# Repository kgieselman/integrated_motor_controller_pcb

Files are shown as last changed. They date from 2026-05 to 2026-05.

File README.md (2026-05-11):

# Integrated Motor Controller PCB

A reusable base board for yearly robotics competitions. The base board handles drive, sensing, control, and radio. Per-season expansion is exposed through a small set of discrete headers (AUX, UART, QWIIC I²C, servo), not a single dedicated mechanism connector.

Adapter boards are named after creature parts: **Fang** (ping pong gripper/launcher), with future adapters extending the menagerie.

## Architecture

```
┌──────────────────────────────────────────────────────────────────┐
│                        Base Board                                │
│                                                                  │
│  ┌───────────────────┐  ┌──────────────────────────────────────┐ │
│  │ Power             │  │  STM32 H563RIT6                      │ │
│  │ 2S/3S → 5V ×2     │  │  250 MHz, 2MB / 640KB                │ │
│  │ (aux + main)      │  │  Y1 ASE-25MHz active oscillator      │ │
│  │ 5V → 3.3V LDO     │  │  BZ buzzer, D6–D9 LEDs               │ │
│  │ USB/batt PowerPath|  └────────────┬─────────────────────────┘ │
│  └───────────────────┘               │                           │
│                                      │                           │
│  ┌───────────────────────────────────┼───────────────┐           │
│  │   DRV8874 ×2 Motor Drivers        │               │           │
│  │   ~9A peak each                   │  Encoders ×2  │           │
│  │   IN1/IN2 + IPROPI                │  TIM4 / TIM8  │           │
│  └───────────────────────────────────┴───────────────┘           │
│                                                                  │
│  Connectors (* = DNP, footprint reserved):                       │
│   J1  RCVR    1×4 pin       — ELRS/CRSF RX/TX + 5 V *            │
│   J2  SWD     2×3 pin       — SWDIO/SWCLK/nRST, 3.3 V *          │
│   J3  ENC 0   1×3 pin       — encoder 0 signal, 3.3 V *          │
│   J4  ENC 1   1×3 pin       — encoder 1 signal, 3.3 V *          │
│   J5  UART    1×3 pin       — expansion UART, JST GH 1.25 mm *   │
│   J6  CH0     1×3 pin       — servo 0, +5V_Aux, GND *            │
│   J7  I2C     1×4 pin       — I2C SDA/SCL, JST SH 1.0 mm *       │
│   J8  CH1     1×3 pin       — servo 1, +5V_Aux, GND *            │
│   J9  I2C     1×4 pin       — I2C SDA/SCL (alt), JST SH 1.0 mm * │
│   J10 CH2     1×3 pin       — servo 2, +5V_Aux, GND *            │
│   J11 USB-C   USB 2.0       — debug / VBUS-powered logic         │
│   J12 VMeter  1×2 pin       — +BATT/GND for external voltmeter * │
│   J13 BATT    XT60          — 2S/3S LiPo input *                 │
│   J14 MOT 0   1×2 pin       — motor 0 out, Molex Micro-Fit 3.0 * │
│   J15 MOT 1   1×2 pin       — motor 1 out, Molex Micro-Fit 3.0 * │
│   JP1/JP2     solder jumpers — CRSF RX path (bridged by design)  │
└──────────────────────────────────────────────────────────────────┘
```

## Key Specs

| | |
|---|---|
| **MCU** | STM32H563RIT6 — Cortex-M33 @ 250 MHz, 2 MB flash, 640 KB SRAM, LQFP-64 |
| **Clock** | Y1 ASE-25.000MHZ — Abracon active oscillator, 4-pin SMD 3.2×2.5 mm |
| **Motor drivers** | 2× DRV8874 (PWP-16, HTSSOP) — IN1/IN2 mode (PMODE driven high), IPROPI current sense |
| **IMU** | LSM6DSV (U6) — 6-axis, SPI1 on PB3/PB4/PB5, CS=PC12, INT1=PD2, INT2=PB8; LGA-14 3×2.5 mm |
| **EEPROM** | M24C64 — 64 Kbit, I²C1 on PB6/PB7, WC=PA9 |
| **RC control** | External CRSF/ELRS receiver via J1 (1×4); JP1/JP2 solder jumpers bridged by default |
| **Servo channels** | 3, powered from +5V_Aux buck |
| **Expansion UART** | JST GH 1.25 mm |
| **I2C expansion** | JST SH 1.0 mm, 1×4 |
| **Power input** | 2S/3S LiPo (7.4–12.6 V) via XT60; USB-C VBUS can power logic rails only |
| **Power topology** | SW1 power switch; SI7157DP; 2N7002; AP63205WU bucks (5V_Aux + 5V); AP1117-33 LDO for 3.3 V |
| **Debug** | SWD, MCU RST, MCU BOOT0, USR button, power switch, LEDs, buzzer |
| **Board** | 4-layer FR4 |

## Schematic Hierarchy

```
integrated_motor_controller.kicad_sch (Root)
├── power_regulator_2s_3s.kicad_sch — Battery input, power switch, bucks, LDO, VBAT sense
├── mcu_h563r.kicad_sch             — STM32H563, Y1 active oscillator, bypass, pin assignments, VCAP, SW2/SW3
├── motor_driver_drv8874.kicad_sch  — DRV8874 (instantiated twice: Motor 0 + Motor 1), motor output connectors
├── imu_lsm6dsv.kicad_sch           — LSM6DSV on SPI1
├── eeprom_m24c64.kicad_sch         — M24C64 on I²C1
├── debug_leds.kicad_sch            — Debug LEDs (×4), buzzer, user button, transistor drivers
└── connector_usb.kicad_sch         — USB-C receptacle + USBLC6-2SC6 ESD + CC pulldowns
```

Servo, encoder, UART, I2C, RCVR, and SWD connectors are placed directly on the root sheet.

## Status

- [x] Schematic hierarchy defined
- [x] Sub-schematics created and wired
- [x] PCB layout complete (KiCad 10)
- [x] Gerber / drill files generated (`gerbers/`)
- [x] ERC clean
- [x] DRC clean
- [x] BOM and pick-and-place outputs
- [ ] First board assembled and tested

## Getting Started

1. Clone this repo
2. Open `integrated_motor_controller.kicad_pro` in KiCad 10+
3. Custom symbols are in `libraries/symbols/` — resolved via the committed `sym-lib-table`
4. Custom footprints are in `libraries/footprints/` — resolved via `fp-lib-table`

## Repo Structure

```
integrated_motor_controller-pcb/
├── integrated_motor_controller.kicad_pro              # KiCad project file — open this
├── integrated_motor_controller.kicad_sch              # Root schematic
├── integrated_motor_controller.kicad_pcb              # PCB layout
├── power_regulator_2s_3s.kicad_sch
├── mcu_h563r.kicad_sch
├── motor_driver_drv8874.kicad_sch
├── imu_lsm6dsv.kicad_sch
├── eeprom_m24c64.kicad_sch
├── debug_leds.kicad_sch
├── connector_usb.kicad_sch
├── gerbers/                       # Gerber + drill files (ready for fab)
├── output/
│   ├── integrated_motor_controller.csv                # BOM export
│   └── integrated_motor_controller.net                # Netlist export
├── libraries/
│   ├── symbols/                   # Custom KiCad symbol libraries (.kicad_sym)
│   ├── footprints/                # Custom KiCad footprint libraries (.kicad_mod)
│   └── 3d_models/                 # STEP/WRL 3D models
├── sym-lib-table                  # Symbol library table (committed — paths are relative)
└── fp-lib-table                   # Footprint library table (committed — paths are relative)
```

## License

[CERN Open Hardware Licence Version 2 - Strongly Reciprocal (CERN-OHL-S-2.0)](LICENSE) © 2026 Kyle Gieselman

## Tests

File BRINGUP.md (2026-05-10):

# Integrated Motor Controller — Bring-Up Notes

Sequencing and constraints for first-board bring-up.

---

## Power-On Sequence

### Pre-power checklist

1. Confirm no shorts on +BATT, 5V, 5V_AUX, 3V3 rails (continuity to GND).
2. Confirm USB-C (J11) and battery (J13) should not both be connected on first power-on.
3. Confirm Y1 (ASE-25.000MHZ) orientation — pin 1 marked with dot; OE pin must be driven or tied appropriately.

### Rail verification (battery path)

1. Connect bench supply to J13 (BATT_IN / XT60) at 7.4 V (2S nominal), current-limited to 500 mA.
2. Press SW1 (power switch).
3. Verify with multimeter:
   - TP9 = 5V ± 100 mV (U4 buck, main rail)
   - TP6 = 5V_AUX ± 100 mV (U2 buck, servo/aux rail)
   - TP8 = 3V3 ± 50 mV (U3 LDO)
   - TP7 = BATT_DIV — should be approximately V_BATT × R_low / (R_high + R_low). JLC resistors are intentionally kept here; per-board ADC calibration (see below) compensates for any divider tolerance.
4. Check current draw at idle (no MCU firmware) — expect < 50 mA.

### Rail verification (USB path)

1. Connect USB-C (J11) with no battery attached.
2. Verify TP8 = 3V3 (logic rails only; 5V bucks do not run from VBUS).
3. Verify TP9 and TP6 are near 0V (bucks off without battery).

---

## STM32 Programming

### SWD (J2) — primary path

J2 pinout (2×3, pin 1 top-left):

```
1  VCC_TARGET (3.3V)   2  SWDIO
3  GND                 4  SWDCLK
5  GND                 6  NRST
```

1. Connect J-Link or ST-Link to J2.
2. Supply power (SW1 on, battery connected, or USB-C connected for 3.3V).
3. Flash with OpenOCD or STM32CubeProgrammer targeting STM32H563RIT6.
4. To force BOOT0 (system bootloader for DFU): hold SW3 (BOOT), press SW2 (RST), release SW2, then release SW3.

---

## Motor Driver Bring-Up (DRV8874)

Both motor channels (U7 for Motor 0, U8 for Motor 1) share the same sheet — verify each independently.

1. Before connecting motors, confirm IPROPI resistor values are correct for expected current range.
2. With MCU firmware loaded, confirm PMODE is driven high (IN1/IN2 control mode).
3. Connect a small test motor to J14 (Motor 0) or J15 (Motor 1) and verify direction control and IPROPI feedback.
4. Do not exceed DRV8874 absolute maximum V_VM (65V); 2S/3S is well within range.

---

## External Receiver (J1)

J1 pinout (1×4, pin 1 = square pad):

```
1  GND
2  +5V
3  CRSF_RX  (MCU←, IO to receiver TX)
4  CRSF_TX  (MCU→, IO to receiver RX)
```

JP1 and JP2 are bridged by default — the CRSF UART is a direct MCU↔J1 connection. No jumper changes required for normal operation.

To connect an ELRS receiver: wire receiver TX → J1 pin 3, receiver RX → J1 pin 4.

---

## Battery Voltage Sense Calibration

The VBAT_SENSE divider uses JLC resistors (not precision-tolerance parts). Each board must be calibrated individually to remove the divider error from ADC readings.

**Procedure (per board):**

1. Connect the calibrated DC supply to J8. Set a known voltage in the 6–9 V range (typical 2S window).
2. Run the ADC calibration routine in the bringup firmware (trigger TBD).
3. The routine samples `ADC1_INP4` (PC4), computes the scale factor against the known supply voltage, and stores the result in EEPROM (address TBD).
4. `Battery.hpp` must apply this stored scale factor at runtime instead of using nominal divider math.
5. Repeat at a second setpoint to verify linearity before signing off.

> **Note:** The calibration trigger mechanism has not been decided yet. Options include a dedicated console command (`cal vbat`), a button-hold sequence at boot, or a flag byte in EEPROM. Update this section once the approach is settled.

---

## Notes

- **SW2** = MCU RST (active low, pulls NRST)
- **SW3** = MCU BOOT0 (hold during reset to enter system bootloader)
- **SW4** = USR (user debug button)
- **SW1** = board power (series with Q1 gate drive)
- **D6** = LED0, **D7** = LED1, **D8** = LED2 — debug LEDs driven by MCU GPIOs; **D9** = PWR indicator LED
- **BZ** = buzzer driven by MCU GPIO; D10 is flyback protection
- **J12** = VMeter — exposes +BATT and GND for an external battery voltage display

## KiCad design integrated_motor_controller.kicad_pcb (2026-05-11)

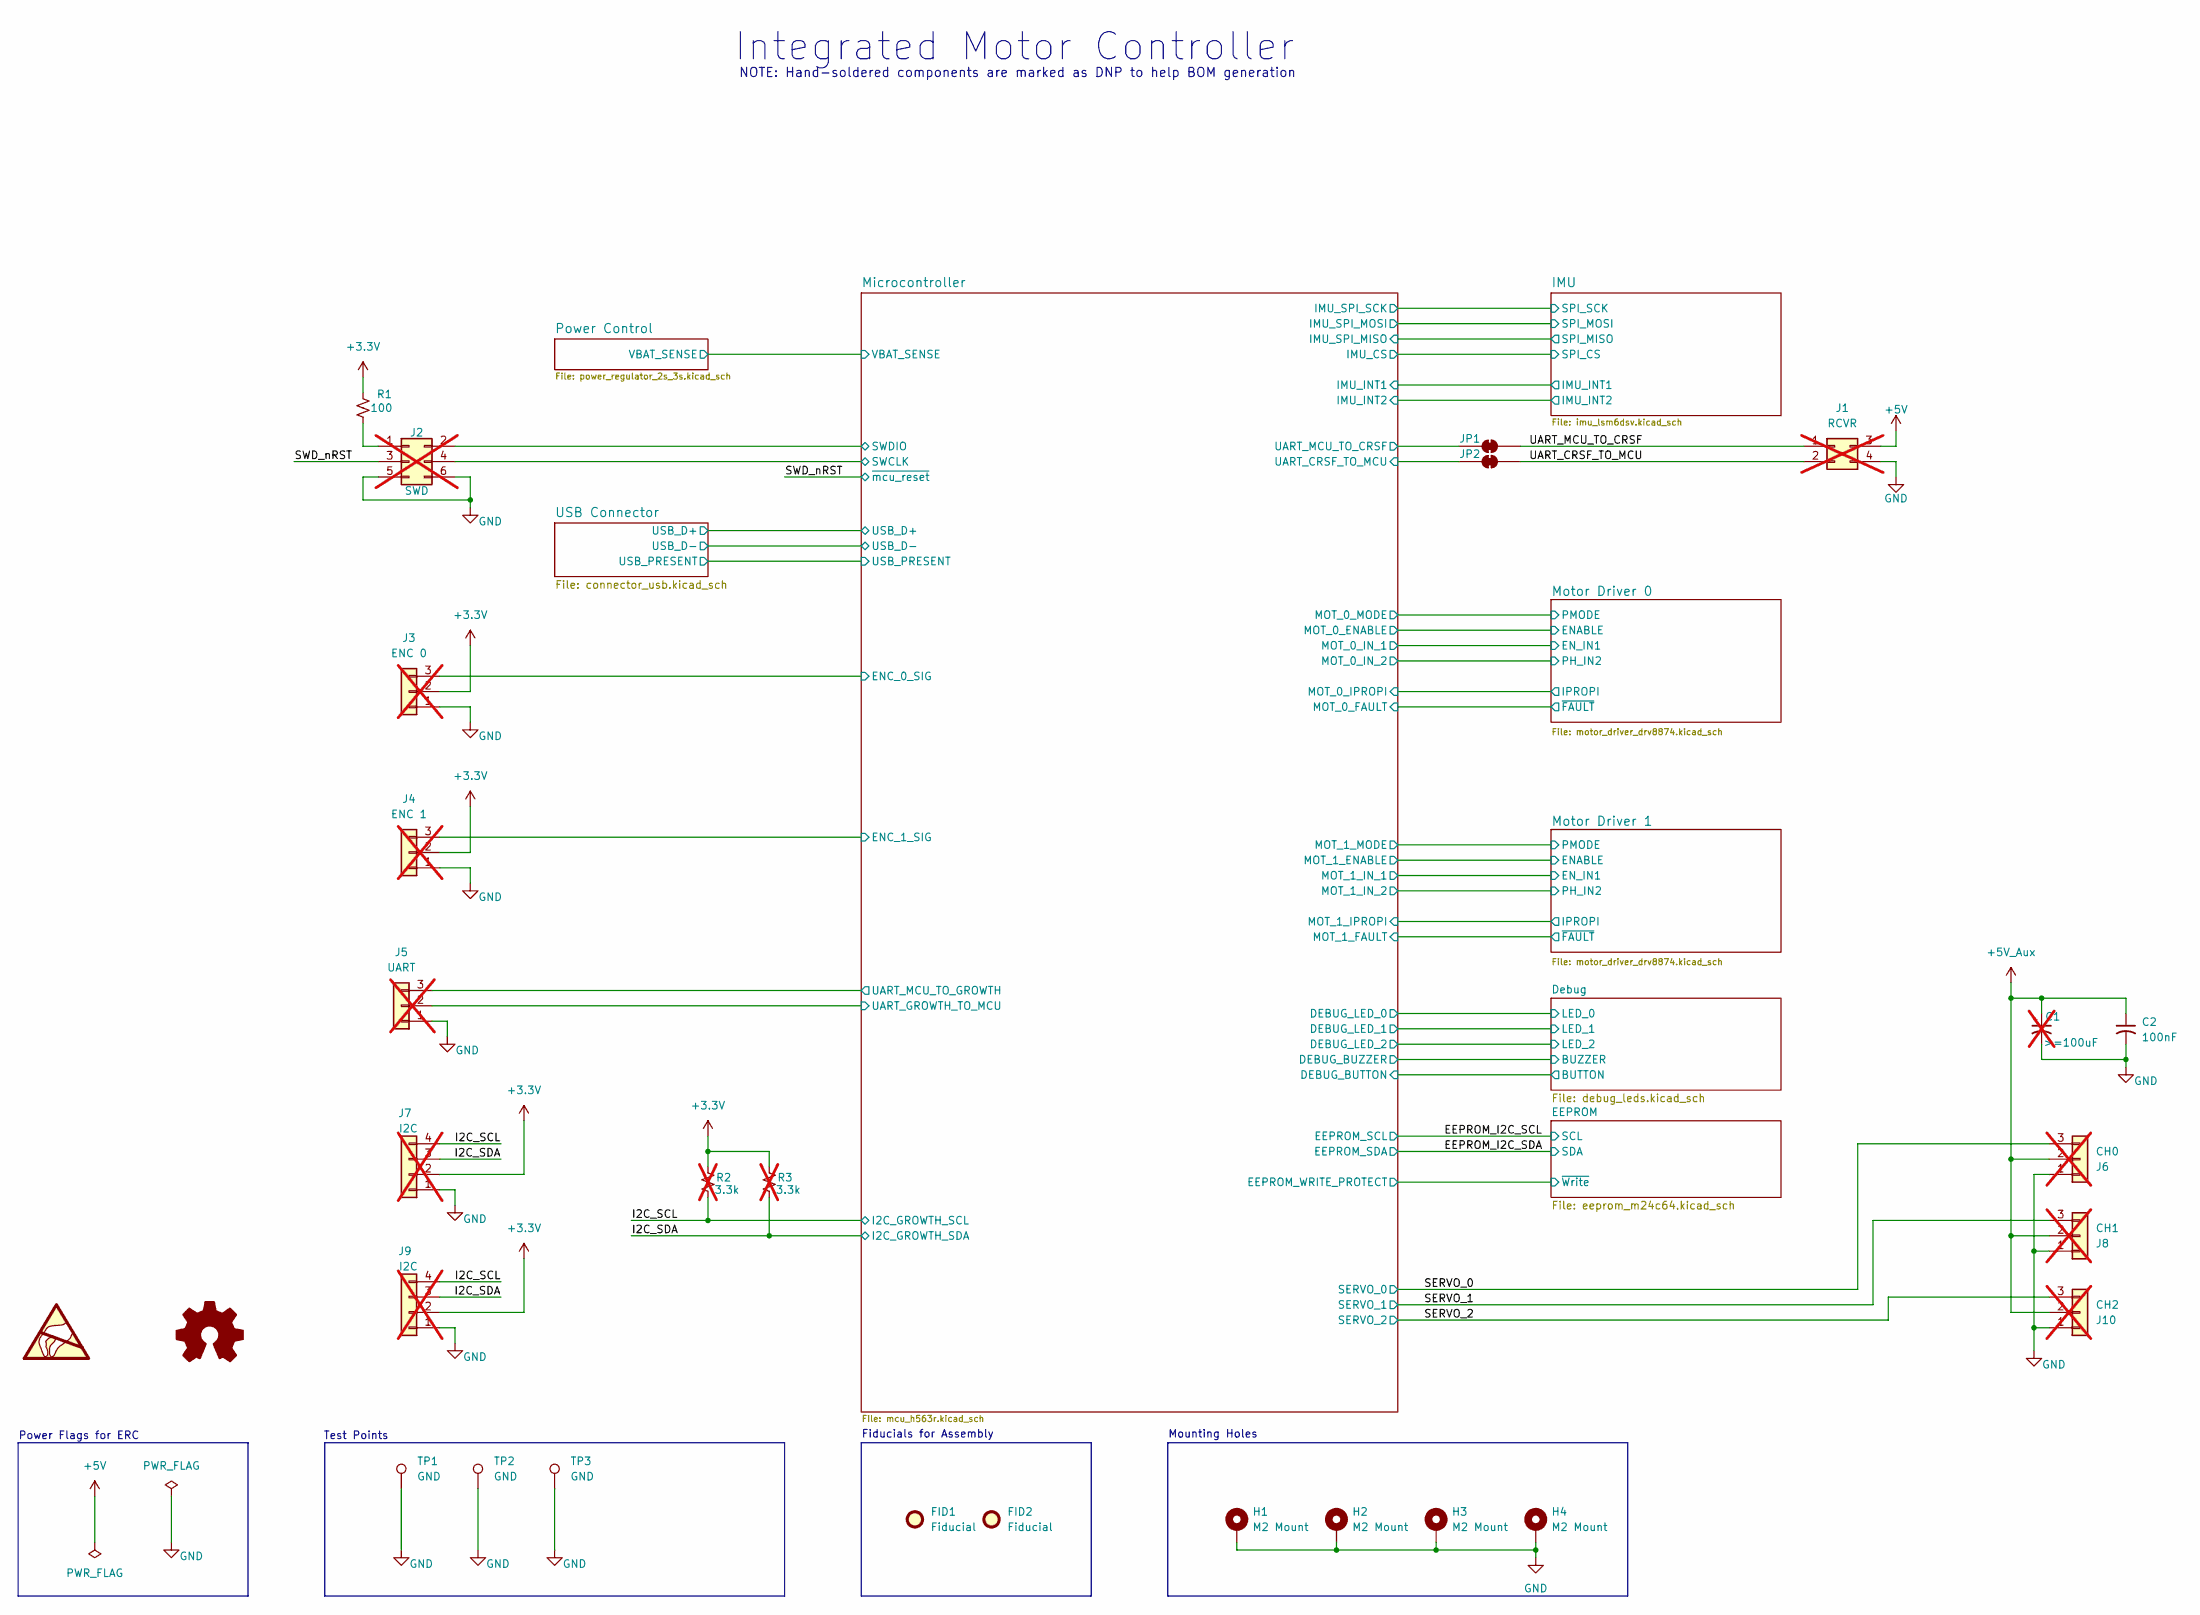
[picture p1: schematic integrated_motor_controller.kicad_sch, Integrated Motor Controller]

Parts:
C1: >=100uF; CP_Radial_D5.0mm_P2.00mm; Part No ---; JLCPCB ---; not fitted
C2: 100nF; C_0603_1608Metric; Part No CC0603KRX7R9BB104; JLCPCB C14663
FID1, FID2: Fiducial; ToolingHole_1.152mm; Part No ---; JLCPCB ---
H1, H2, H3, H4: M2 Mount; MountingHole_2.2mm_M2_Pad_Via; Part No ---; JLCPCB ---
J1: RCVR; PinHeader_1x04_P2.54mm_Vertical; Part No ---; JLCPCB ---; not fitted
J2: SWD; PinHeader_2x03_P2.54mm_Vertical; Part No ---; JLCPCB ---; not fitted
J3: ENC 0; PinHeader_1x03_P2.54mm_Vertical; Part No ---; JLCPCB ---; not fitted
J4: ENC 1; PinHeader_1x03_P2.54mm_Vertical; Part No ---; JLCPCB ---; not fitted
J5: UART; JST_GH_BM03B-GHS-TBT_1x03-1MP_P1.25mm_Vertical; Part No TODO; JLCPCB ---; not fitted
J6: CH0; PinHeader_1x03_P2.54mm_Vertical; Part No ----; JLCPCB ----; not fitted
J7, J9: I2C; JST_SH_BM04B-SRSS-TB_1x04-1MP_P1.00mm_Vertical; Part No TODO; JLCPCB ---; not fitted
J8: CH1; PinHeader_1x03_P2.54mm_Vertical; Part No ----; JLCPCB ----; not fitted
J10: CH2; PinHeader_1x03_P2.54mm_Vertical; Part No ----; JLCPCB ----; not fitted
JP1, JP2: SolderJumper_2_Bridged; SolderJumper-2_P1.3mm_Bridged_Pad1.0x1.5mm; Part No ---; JLCPCB ---
R1: 100; R_0603_1608Metric; Part No 0603WAF1000T5E; JLCPCB C22775
R2, R3: 3.3k; R_0603_1608Metric; Part No 0603WAF3301T5E; JLCPCB C22978; not fitted
SYM1: SYM_ESD_Large; ESD-Logo_6.6x6mm_SilkScreen; Part No ---; JLCPCB ---
SYM2: Logo_Open_Hardware_Small; KiCad-Logo2_6mm_SilkScreen; Part No ---; JLCPCB ---
TP1, TP2, TP3: GND; TestPoint_Pad_D1.0mm; Part No ---; JLCPCB ---

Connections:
+5V: J1.3; also elsewhere on the board
+5V_Aux: C1.1, C2.1, J6.2, J8.2, J10.2; also elsewhere on the board
/I2C_SCL: J7.4, J9.4, R2.1; also elsewhere on the board
/I2C_SDA: J7.3, J9.3, R3.1; also elsewhere on the board
/Microcontroller/ENC_0_SIG: J3.3; also elsewhere on the board
/Microcontroller/ENC_1_SIG: J4.3; also elsewhere on the board
/Microcontroller/SWCLK: J2.4; also elsewhere on the board
/Microcontroller/SWDIO: J2.2; also elsewhere on the board
/Microcontroller/UART_CRSF_TO_MCU: JP2.1 (A); also elsewhere on the board
/Microcontroller/UART_GROWTH_TO_MCU: J5.2; also elsewhere on the board
/Microcontroller/UART_MCU_TO_CRSF: JP1.1 (A); also elsewhere on the board
/Microcontroller/UART_MCU_TO_GROWTH: J5.3; also elsewhere on the board
/SERVO_0: J6.3; also elsewhere on the board
/SERVO_1: J8.3; also elsewhere on the board
/SERVO_2: J10.3; also elsewhere on the board
/SWD_nRST: J2.3; also elsewhere on the board
/UART_CRSF_TO_MCU: J1.2, JP2.2 (B)
/UART_MCU_TO_CRSF: J1.1, JP1.2 (B)
unnamed: J2.1, R1.2

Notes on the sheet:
Fiducials for Assembly
Test Points
Integrated Motor Controller
Power Flags for ERC
Mounting Holes
NOTE: Hand-soldered components are marked as DNP to help BOM generation

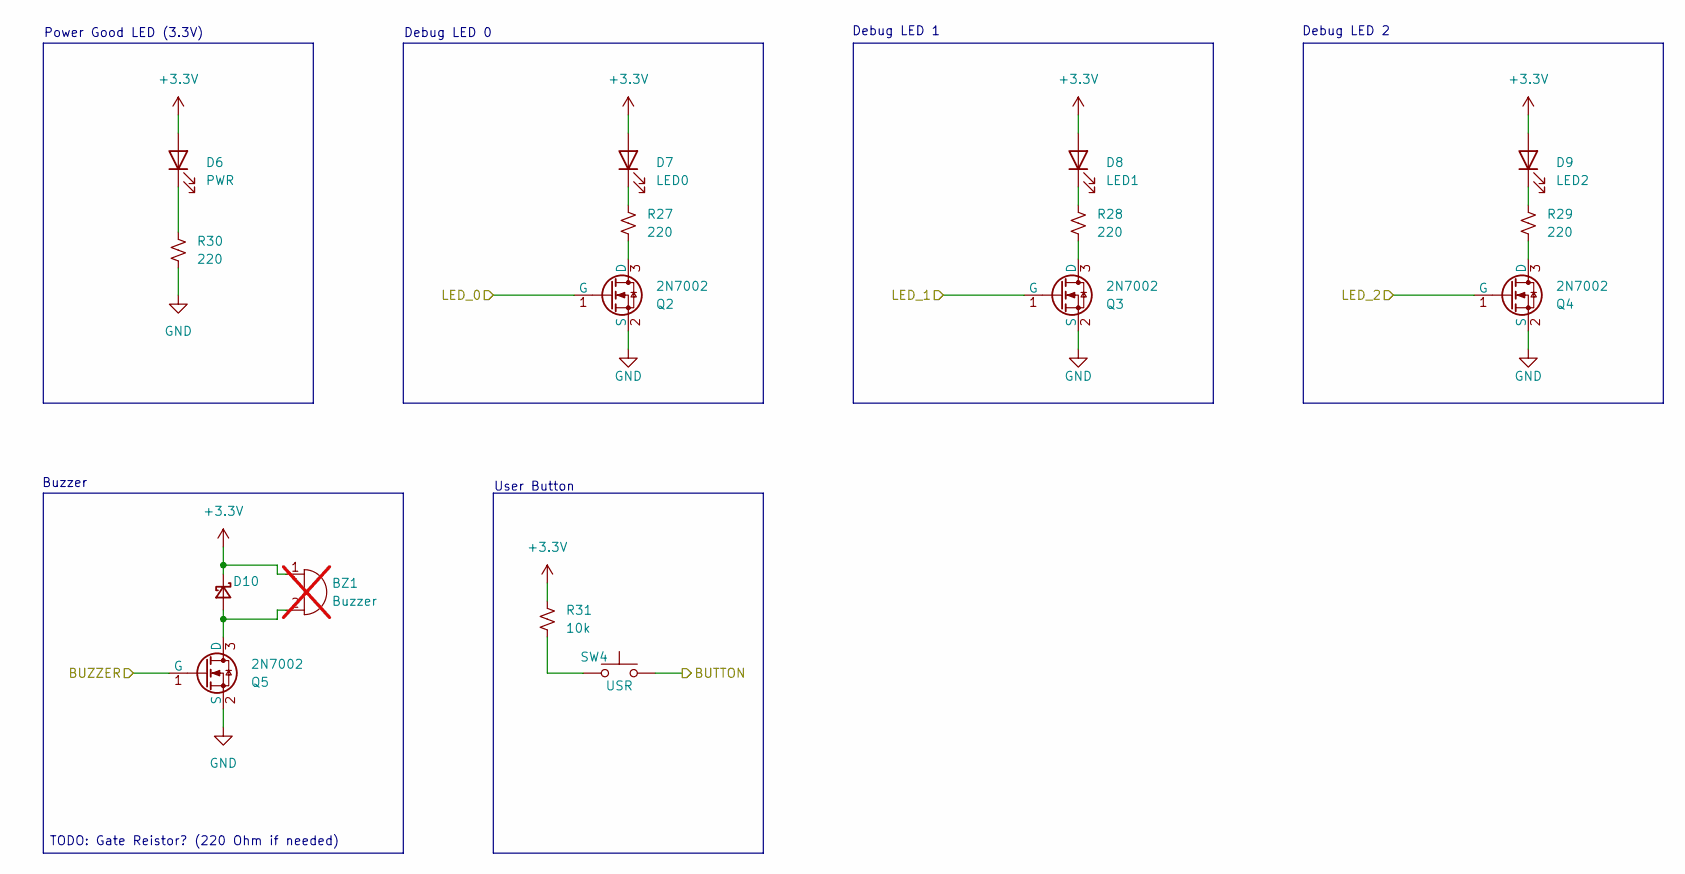
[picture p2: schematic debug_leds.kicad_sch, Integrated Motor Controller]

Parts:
BZ1: Buzzer; MagneticBuzzer_PUI_AT-0927-TT-6-R; Part No AT-0927-TT-6-R; JLCPCB ---; not fitted
D6: PWR; LED_0603_1608Metric; Part No KT-0603R; JLCPCB C2286
D7: LED0; LED_0603_1608Metric; Part No KT-0603R; JLCPCB C2286
D8: LED1; LED_0603_1608Metric; Part No KT-0603R; JLCPCB C2286
D9: LED2; LED_0603_1608Metric; Part No KT-0603R; JLCPCB C2286
D10: Schottky; D_SOD-123; Part No B5819W SL; JLCPCB C8598
Q2, Q3, Q4, Q5: 2N7002; SOT-23; Part No 2N7002; JLCPCB C8545
R27, R28, R29, R30: 220; R_0603_1608Metric; Part No 0603WAF2200T5E; JLCPCB C22962
R31: 10k; R_0603_1608Metric; Part No 0603WAF1002T5E; JLCPCB C25804
SW4: USR; SW_SPST_TS-1088-xR020; Part No TS-1088-AR02016; JLCPCB C720477

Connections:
/Debug/BUTTON: SW4.2; also elsewhere on the board
/Debug/BUZZER: Q5.1 (G); also elsewhere on the board
/Debug/LED_0: Q2.1 (G); also elsewhere on the board
/Debug/LED_1: Q3.1 (G); also elsewhere on the board
/Debug/LED_2: Q4.1 (G); also elsewhere on the board
unnamed: BZ1.2 (-), D10.2 (A), Q5.3 (D)
unnamed: D7.1 (K), R27.1
unnamed: D8.1 (K), R28.1
unnamed: Q2.3 (D), R27.2
unnamed: Q3.3 (D), R28.2
unnamed: R31.1, SW4.1

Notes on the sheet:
Debug LED 2
Buzzer
User Button
Debug LED 0
Power Good LED (3.3V)
Debug LED 1
TODO: Gate Reistor? (220 Ohm if needed)

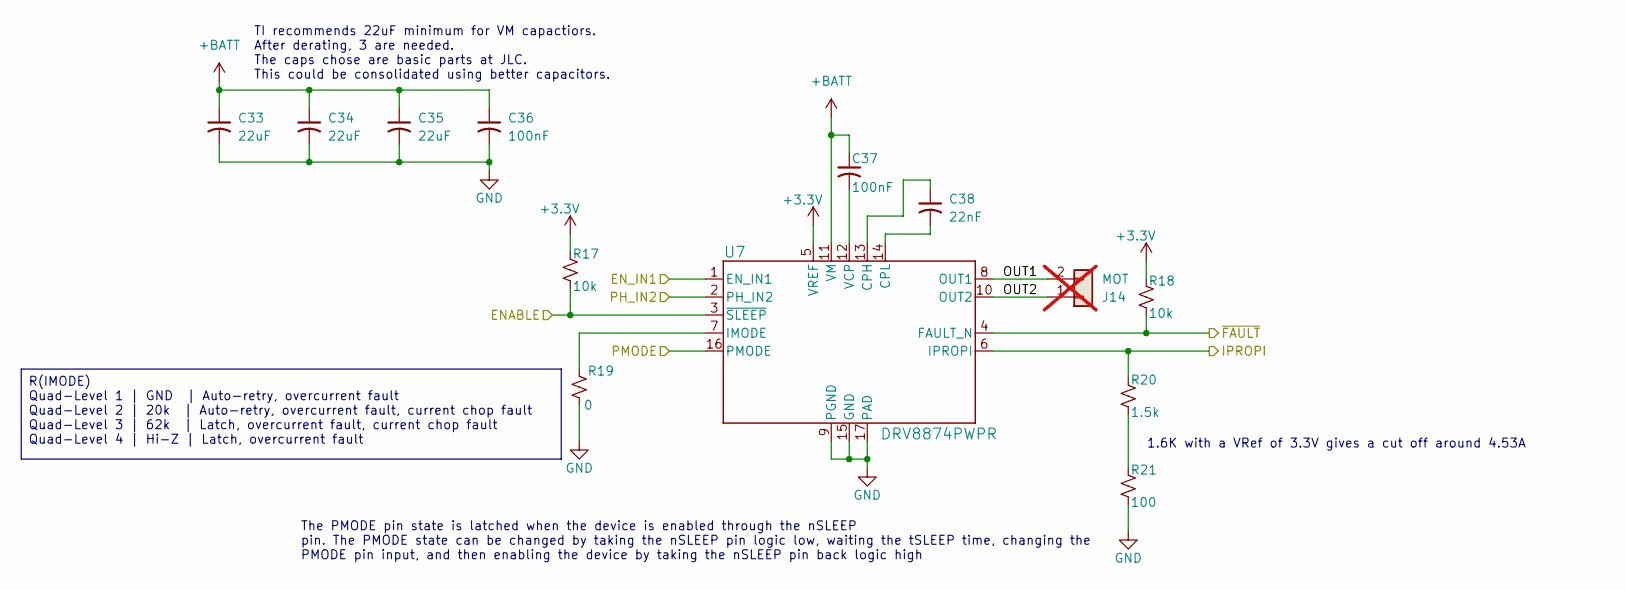
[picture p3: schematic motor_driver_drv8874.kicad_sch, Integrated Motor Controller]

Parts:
C33, C34, C35: 22uF; C_1206_3216Metric; Part No CL31A226KAHNNNE; JLCPCB C12891
C36, C37: 100nF; C_0603_1608Metric; Part No CC0603KRX7R9BB104; JLCPCB C14663
C38: 22nF; C_0603_1608Metric; Part No CL10B223KB8NNNC; JLCPCB C21122
J14: MOT; Molex_Micro-Fit_3.0_43650-0215_1x02_P3.00mm_Vertical; Part No 0436500215; JLCPCB ---; not fitted
R17, R18: 10k; R_0603_1608Metric; Part No 0603WAF1002T5E; JLCPCB C25804
R19: 0; R_0805_2012Metric; Part No 0805W8F0000T5E; JLCPCB C17477
R20: 1.5k; R_0805_2012Metric; Part No 0805W8F1501T5E; JLCPCB C4310
R21: 100; R_0805_2012Metric; Part No 0805W8F1000T5E; JLCPCB C17408
U7: DRV8874PWPR; PWP0016J_N; Part No DRV8874PWPR; JLCPCB C1855818

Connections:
+BATT: C33.1, C34.1, C35.1, C36.1, C37.1, U7.11 (VM); also elsewhere on the board
/Microcontroller/MOT_0_ENABLE: R17.1, U7.3 (~SLEEP); also elsewhere on the board
/Microcontroller/MOT_0_FAULT: R18.1, U7.4 (FAULT_N); also elsewhere on the board
/Microcontroller/MOT_0_IN_1: U7.1 (EN_IN1); also elsewhere on the board
/Microcontroller/MOT_0_IN_2: U7.2 (PH_IN2); also elsewhere on the board
/Microcontroller/MOT_0_IPROPI: R20.2, U7.6 (IPROPI); also elsewhere on the board
/Microcontroller/MOT_0_MODE: U7.16 (PMODE); also elsewhere on the board
/Motor Driver 0/OUT1: J14.2, U7.8 (OUT1)
/Motor Driver 0/OUT2: J14.1, U7.10 (OUT2)
unnamed: R20.1, R21.2
unnamed: C38.1, U7.13 (CPH)
unnamed: C38.2, U7.14 (CPL)
unnamed: R19.1, U7.7 (IMODE)
unnamed: C37.2, U7.12 (VCP)

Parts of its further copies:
C39, C40, C41: 22uF; C_1206_3216Metric; Part No CL31A226KAHNNNE; JLCPCB C12891
C42, C43: 100nF; C_0603_1608Metric; Part No CC0603KRX7R9BB104; JLCPCB C14663
C44: 22nF; C_0603_1608Metric; Part No CL10B223KB8NNNC; JLCPCB C21122
J15: MOT; Molex_Micro-Fit_3.0_43650-0215_1x02_P3.00mm_Vertical; Part No 0436500215; JLCPCB ---; not fitted
R22, R23: 10k; R_0603_1608Metric; Part No 0603WAF1002T5E; JLCPCB C25804
R24: 0; R_0805_2012Metric; Part No 0805W8F0000T5E; JLCPCB C17477
R25: 1.5k; R_0805_2012Metric; Part No 0805W8F1501T5E; JLCPCB C4310
R26: 100; R_0805_2012Metric; Part No 0805W8F1000T5E; JLCPCB C17408
U8: DRV8874PWPR; PWP0016J_N; Part No DRV8874PWPR; JLCPCB C1855818

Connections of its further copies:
+BATT: C39.1, C40.1, C41.1, C42.1, C43.1, U8.11 (VM); also elsewhere on the board
/Microcontroller/MOT_1_ENABLE: R22.1, U8.3 (~SLEEP); also elsewhere on the board
/Microcontroller/MOT_1_FAULT: R23.1, U8.4 (FAULT_N); also elsewhere on the board
/Microcontroller/MOT_1_IN_1: U8.1 (EN_IN1); also elsewhere on the board
/Microcontroller/MOT_1_IN_2: U8.2 (PH_IN2); also elsewhere on the board
/Microcontroller/MOT_1_IPROPI: R25.2, U8.6 (IPROPI); also elsewhere on the board
/Microcontroller/MOT_1_MODE: U8.16 (PMODE); also elsewhere on the board
/Motor Driver 1/OUT1: J15.2, U8.8 (OUT1)
/Motor Driver 1/OUT2: J15.1, U8.10 (OUT2)
unnamed: R25.1, R26.2
unnamed: C44.1, U8.13 (CPH)
unnamed: C44.2, U8.14 (CPL)
unnamed: R24.1, U8.7 (IMODE)
unnamed: C43.2, U8.12 (VCP)

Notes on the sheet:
1.6K with a VRef of 3.3V gives a cut off around 4.53A
The PMODE pin state is latched when the device is enabled through the nSLEEP pin. The PMODE state can be changed by taking the nSLEEP pin logic low, waiting the tSLEEP time, changing the PMODE pin input, and then enabling the device by taking the nSLEEP pin back logic high
TI recommends 22uF minimum for VM capactiors. After derating, 3 are needed. The caps chose are basic parts at JLC. This could be consolidated using better capacitors.
R(IMODE) Quad-Level 1 | GND | Auto-retry, overcurrent fault Quad-Level 2 | 20k | Auto-retry, overcurrent fault, current chop fault Quad-Level 3 | 62k | Latch, overcurrent fault, current chop fault Quad-Level 4 | Hi-Z | Latch, overcurrent fault

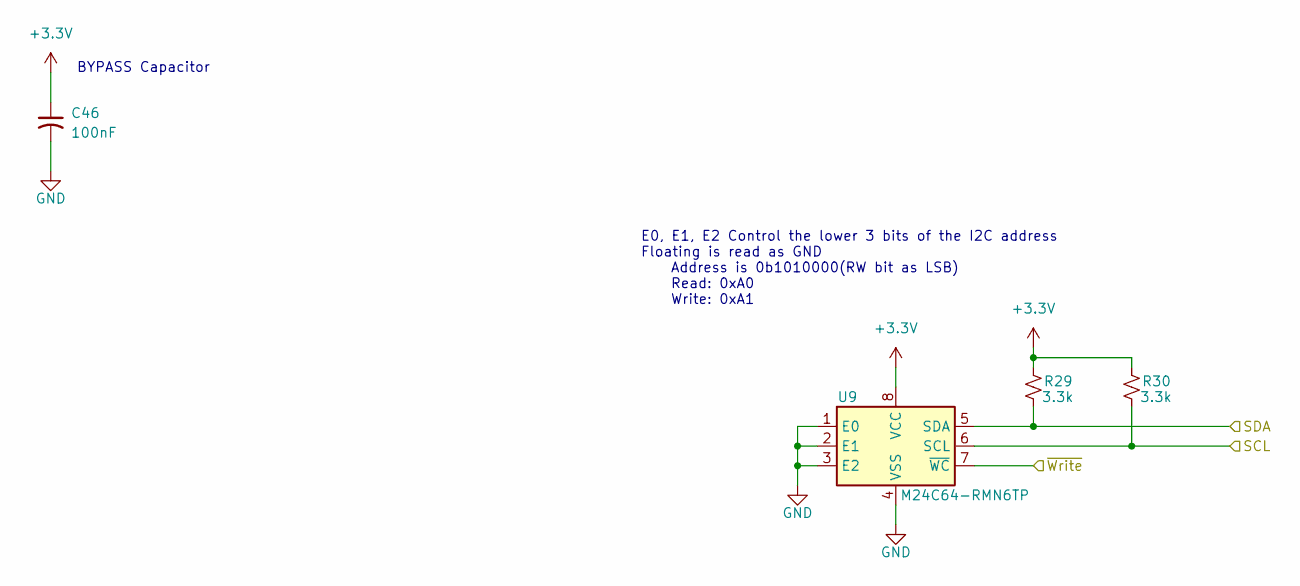
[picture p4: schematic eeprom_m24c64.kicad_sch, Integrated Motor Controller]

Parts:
C46: 100nF; C_0603_1608Metric; Part No CC0603KRX7R9BB104; JLCPCB C14663
R29, R30: 3.3k; R_0603_1608Metric; Part No 0603WAF3301T5E; JLCPCB C22978
U9: M24C64-RMN6TP; SOIC-8_3.9x4.9mm_P1.27mm; Part No M24C64-RMN6TP; JLCPCB C79988

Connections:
/EEPROM/~Write: U9.7 (~WC); also elsewhere on the board

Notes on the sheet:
E0, E1, E2 Control the lower 3 bits of the I2C address Floating is read as GND Address is 0b1010000(RW bit as LSB) Read: 0xA0 Write: 0xA1
BYPASS Capacitor

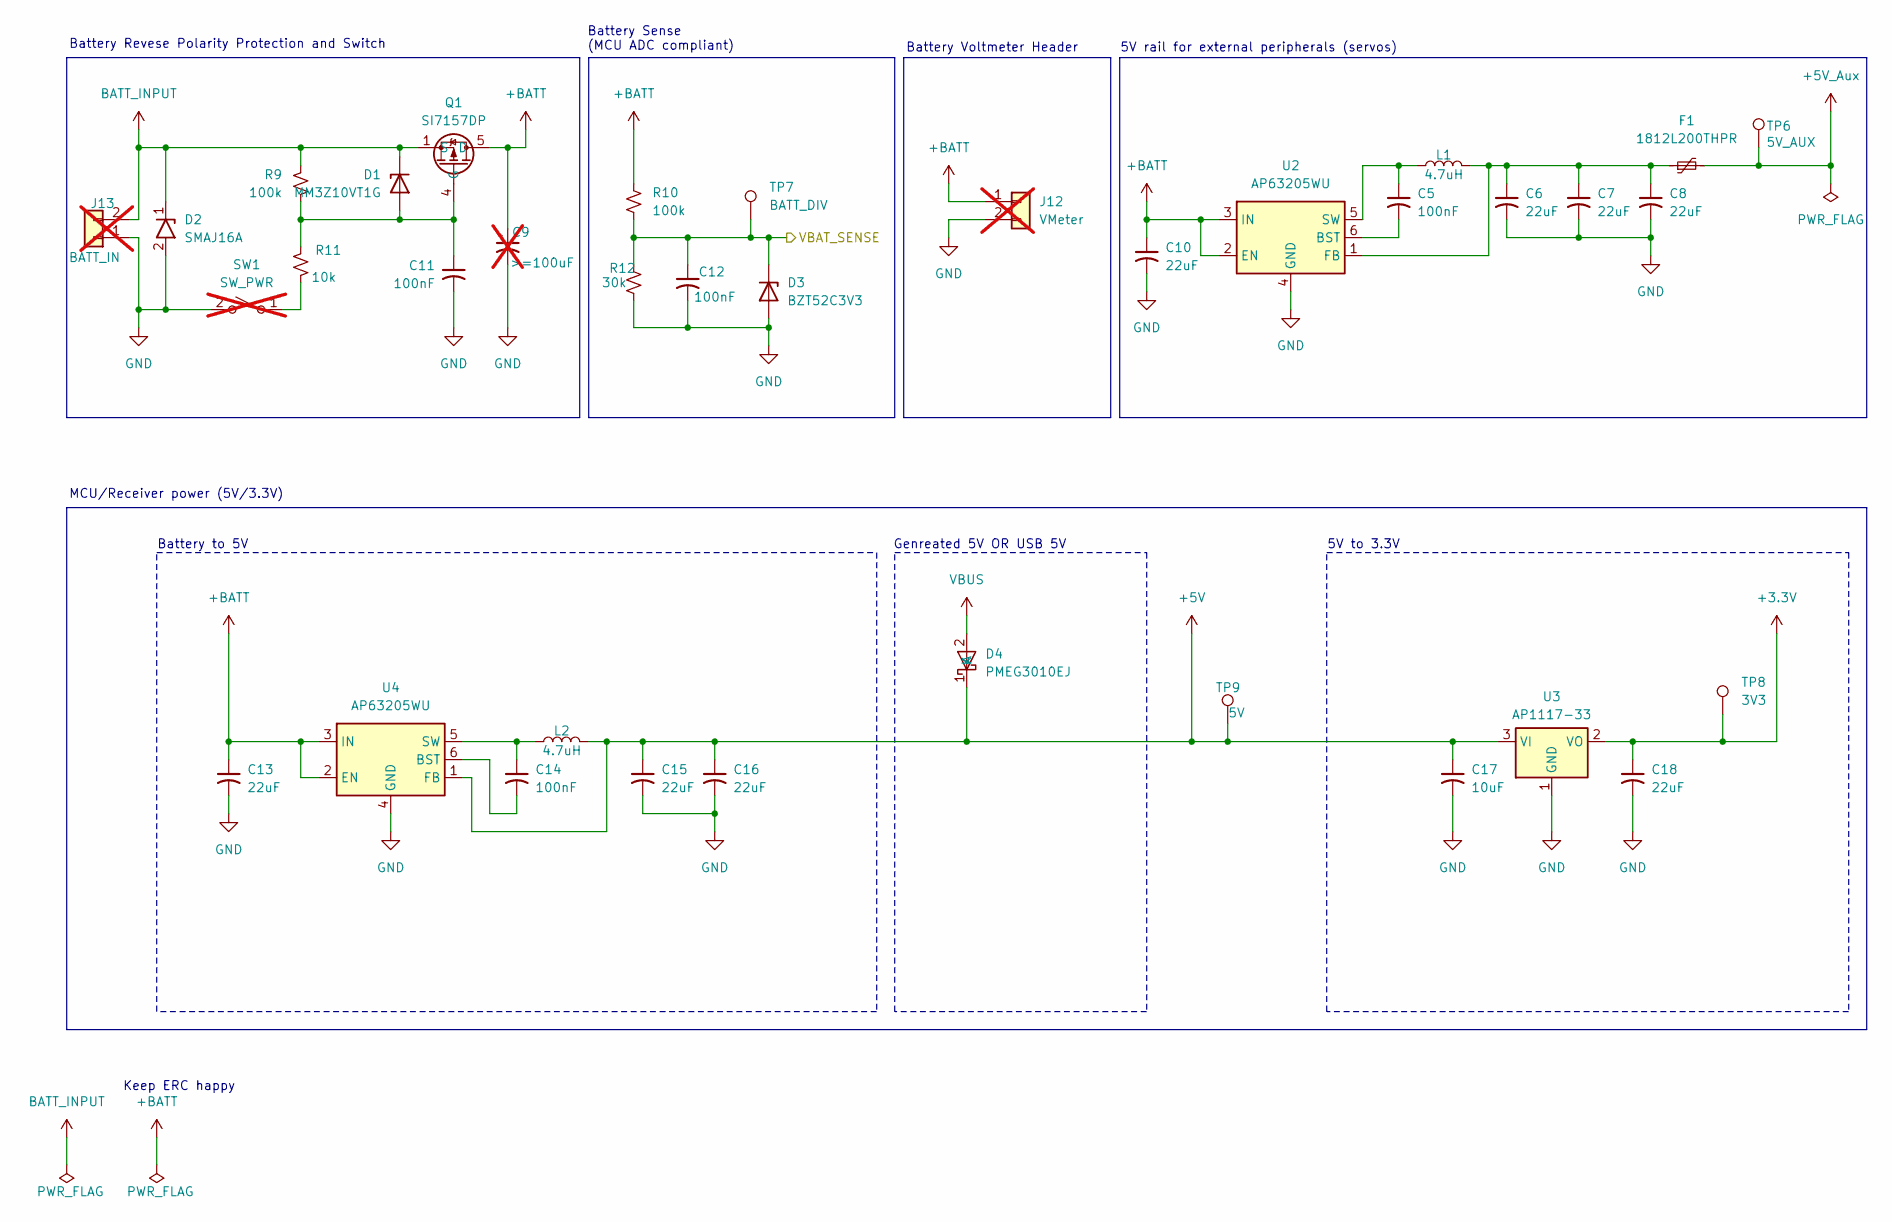
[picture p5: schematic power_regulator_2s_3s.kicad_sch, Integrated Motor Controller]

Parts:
C5, C11, C12, C14: 100nF; C_0603_1608Metric; Part No CC0603KRX7R9BB104; JLCPCB C14663
C6, C7, C8, C10, C13, C15, C16, C18: 22uF; C_1206_3216Metric; Part No CL31A226KAHNNNE; JLCPCB C12891
C9: >=100uF; CP_Radial_D5.0mm_P2.00mm; Part No ---; JLCPCB ---; not fitted
C17: 10uF; C_0603_1608Metric; Part No CL10A106MA8NRNC; JLCPCB C96446
D1: MM3Z10VT1G; D_SOD-323; Part No MM3Z10VT1G; JLCPCB C39057
D2: SMAJ16A; D_SMA; Part No SMAJ16A; JLCPCB C74561
D3: BZT52C3V3; D_SOD-123; Part No BZT52C3V3-7-F; JLCPCB C151564
D4: PMEG3010EJ; D_SOD-323F; Part No PMEG3010EJ,115; JLCPCB C255586
F1: 1812L200THPR; Fuse_1812_4532Metric; Part No 1812L200THPR; JLCPCB C207074
J12: VMeter; PinHeader_1x02_P2.54mm_Vertical; Part No ---; JLCPCB ---; not fitted
J13: BATT_IN; AMASS_XT60-M_1x02_P7.20mm_Vertical; Part No ---; JLCPCB ---; not fitted
L1, L2: 4.7uH; L_Sunlord_MWSA0503S; Part No MWSA0503S-4R7MT; JLCPCB C408410
Q1: SI7157DP; PowerPAK_SO-8_Single; Part No SI7157DP-T1-GE3; JLCPCB C3279562
R9, R10: 100k; R_0603_1608Metric; Part No 0603WAF1003T5E; JLCPCB C25803
R11: 10k; R_0603_1608Metric; Part No 0603WAF1002T5E; JLCPCB C25804
R12: 30k; R_0603_1608Metric; Part No 0603WAF3002T5E; JLCPCB C22984
SW1: SW_PWR; PinHeader_1x02_P2.54mm_Vertical; Part No ---; JLCPCB ---; not fitted
TP6: 5V_AUX; TestPoint_Pad_D1.0mm; Part No ---; JLCPCB ---
TP7: BATT_DIV; TestPoint_Pad_D1.0mm; Part No ---; JLCPCB ---
TP8: 3V3; TestPoint_Pad_D1.0mm; Part No ---; JLCPCB ---
TP9: 5V; TestPoint_Pad_D1.0mm; Part No ---; JLCPCB ---
U2, U4: AP63205WU; TSOT-23-6; Part No AP63205WU-7; JLCPCB C2071056
U3: AP1117-33; SOT-223-3_TabPin2; Part No AMS1117-3.3; JLCPCB C6186

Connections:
+5V: C15.1, C16.1, C17.1, D4.1 (K), L2.2, TP9.1 (1_1), U3.3 (VI), U4.1 (FB); also elsewhere on the board
+5V_Aux: F1.2, TP6.1 (1_1); also elsewhere on the board
+BATT: C9.1, C10.1, C13.1, J12.1, Q1.5 (D), R10.1, U2.2 (EN), U2.3 (IN), U4.2 (EN), U4.3 (IN); also elsewhere on the board
/Microcontroller/VBAT_SENSE: C12.1, D3.1 (K), R10.2, R12.1, TP7.1 (1_1); also elsewhere on the board
BATT_INPUT: D1.1 (K), D2.1 (A1), J13.2, Q1.1 (S), Q1.2 (S), Q1.3 (S), R9.2
unnamed: C11.1, D1.2 (A), Q1.4 (G), R9.1, R11.2
unnamed: R11.1, SW1.1 (A)
unnamed: C5.2, U2.6 (BST)
unnamed: C6.1, C7.1, C8.1, F1.1, L1.2, U2.1 (FB)
unnamed: C5.1, L1.1, U2.5 (SW)
unnamed: C14.2, U4.6 (BST)
unnamed: C14.1, L2.1, U4.5 (SW)
VBUS: D4.2 (A); also elsewhere on the board

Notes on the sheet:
Battery to 5V
Battery Sense (MCU ADC compliant)
Battery Revese Polarity Protection and Switch
Battery Voltmeter Header
5V to 3.3V
MCU/Receiver power (5V/3.3V)
Keep ERC happy
Genreated 5V OR USB 5V
5V rail for external peripherals (servos)

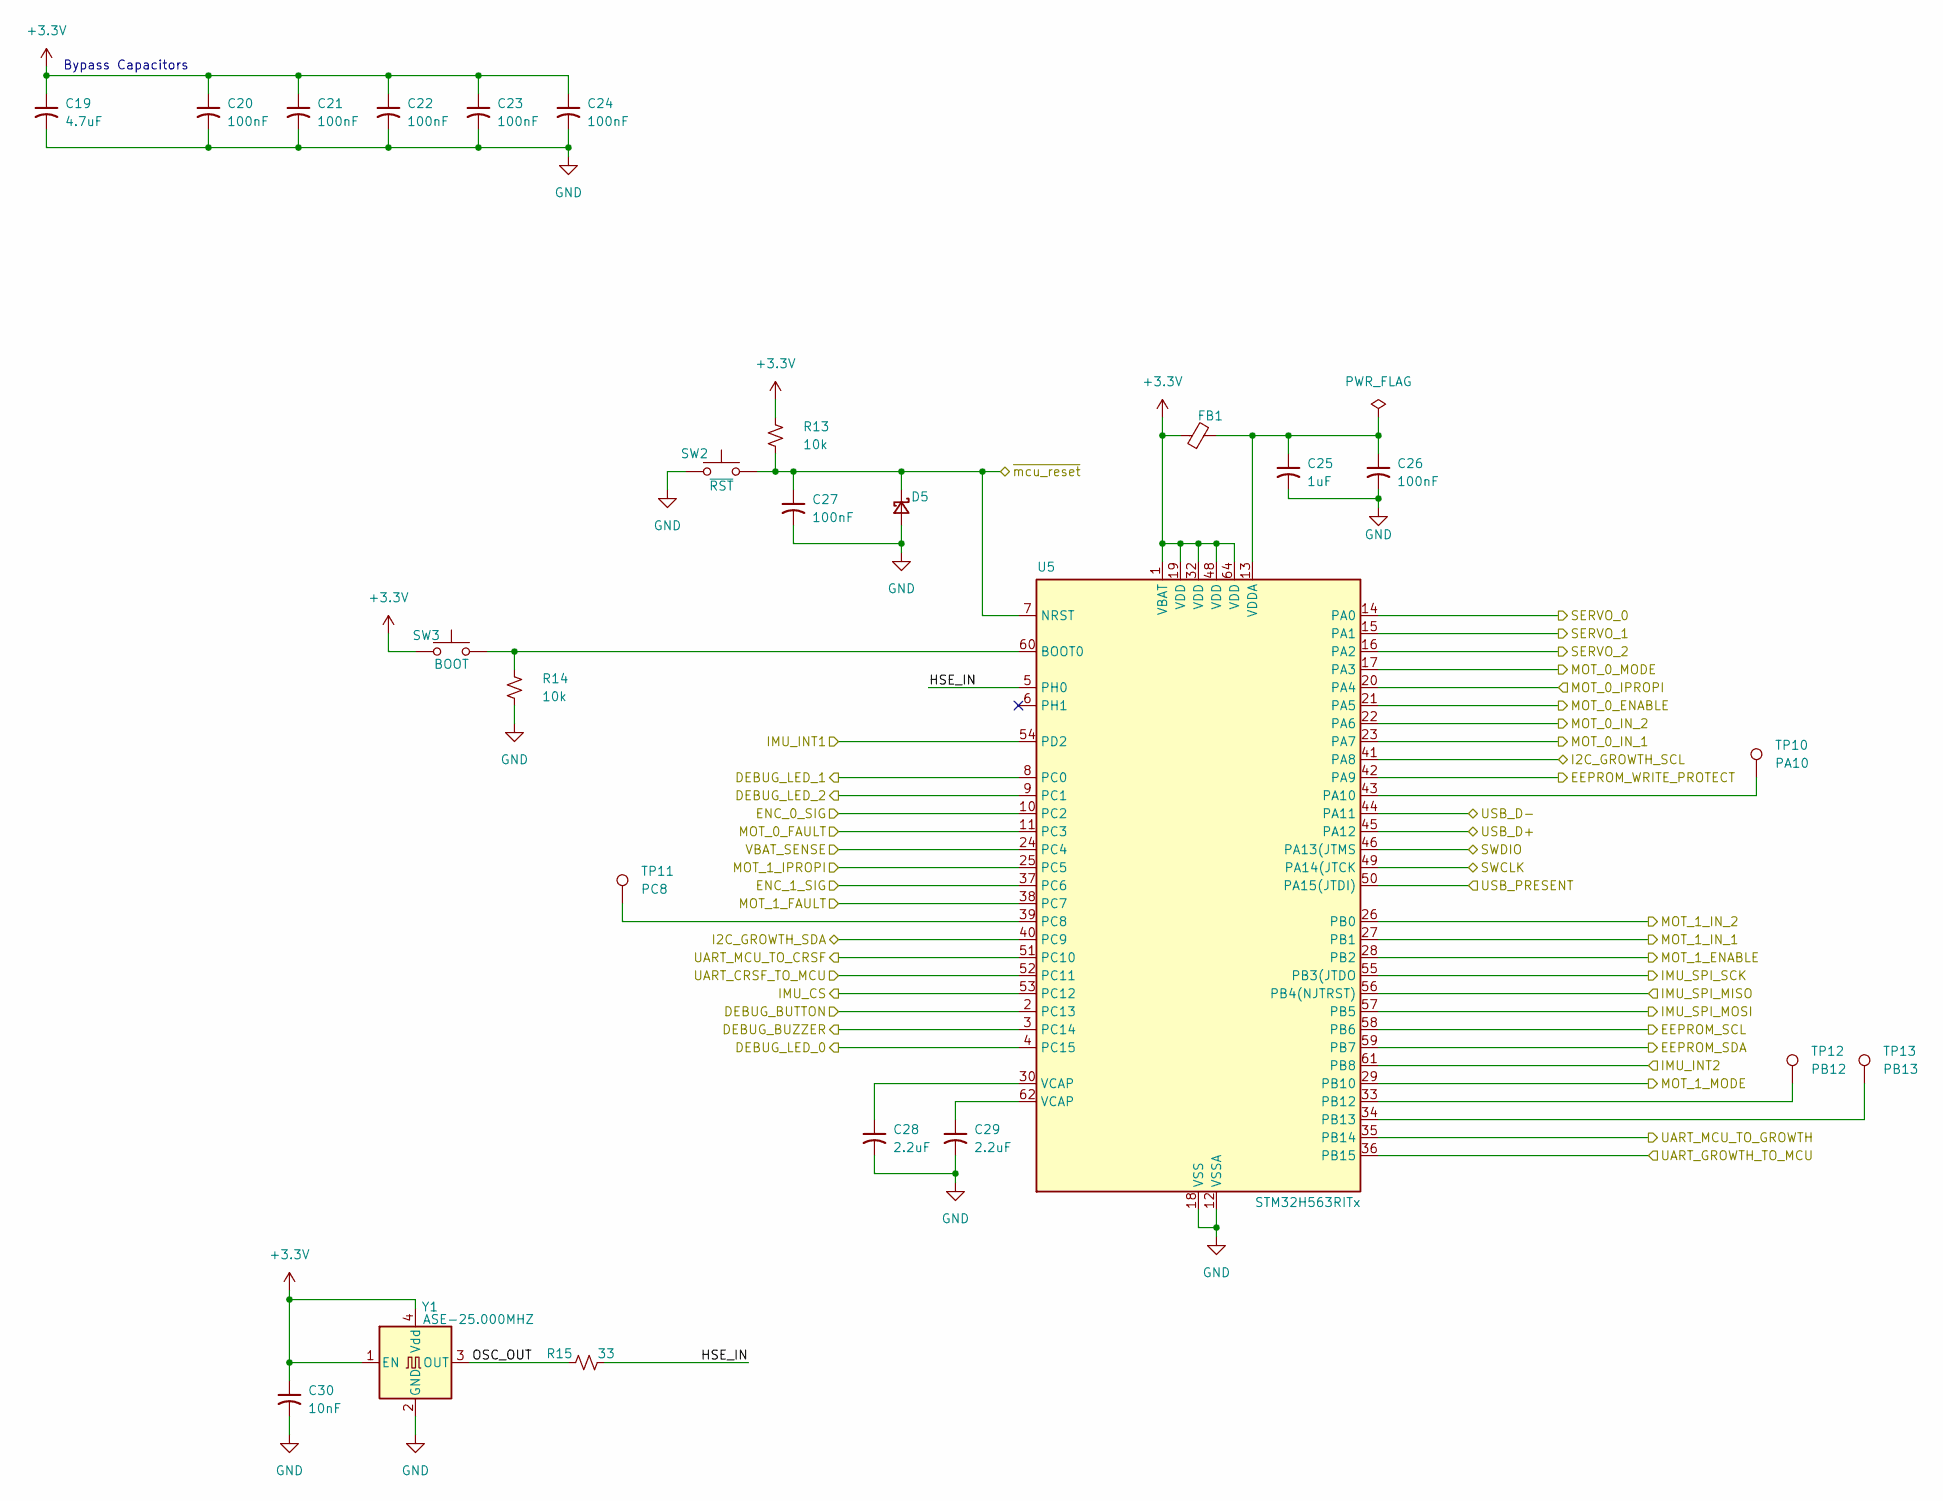
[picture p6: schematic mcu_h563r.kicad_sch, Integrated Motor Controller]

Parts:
C19: 4.7uF; C_0603_1608Metric; Part No CL10A475KO8NNNC; JLCPCB C19666
C20, C21, C22, C23, C24, C26, C27: 100nF; C_0603_1608Metric; Part No CC0603KRX7R9BB104; JLCPCB C14663
C25: 1uF; C_0603_1608Metric; Part No CL10A105KB8NNNC; JLCPCB C15849
C28, C29: 2.2uF; C_0603_1608Metric; Part No CL10A225KO8NNNC; JLCPCB C23630
C30: 10nF; C_0603_1608Metric; Part No 0603B103K500NT; JLCPCB C57112
D5: Schottky; D_SOD-123; Part No B5819W SL; JLCPCB C8598
FB1: Ferrite; L_0805_2012Metric; Part No GZ2012D601TF; JLCPCB C1017
R13, R14: 10k; R_0603_1608Metric; Part No 0603WAF1002T5E; JLCPCB C25804
R15: 33; R_0603_1608Metric; Part No 0603WAF330JT5E; JLCPCB C23140
SW2: ~{RST}; SW_SPST_TS-1088-xR020; Part No TS-1088-AR02016; JLCPCB C720477
SW3: BOOT; SW_SPST_TS-1088-xR020; Part No TS-1088-AR02016; JLCPCB C720477
TP10: PA10; TestPoint_Pad_D1.0mm; Part No ---; JLCPCB ---
TP11: PC8; TestPoint_Pad_D1.0mm; Part No ---; JLCPCB ---
TP12: PB12; TestPoint_Pad_D1.0mm; Part No ---; JLCPCB ---
TP13: PB13; TestPoint_Pad_D1.0mm; Part No ---; JLCPCB ---
U5: STM32H563RITx; LQFP-64_10x10mm_P0.5mm; Part No STM32H563RIT6; JLCPCB C20619634
Y1: ASE-25.000MHZ; Oscillator_SMD_Abracon_ASE-4Pin_3.2x2.5mm; Part No ASE-25.000MHZ-L-R-T; JLCPCB C596952

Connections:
/Debug/BUTTON: U5.2 (PC13); also elsewhere on the board
/Debug/BUZZER: U5.3 (PC14); also elsewhere on the board
/Debug/LED_0: U5.4 (PC15); also elsewhere on the board
/Debug/LED_1: U5.8 (PC0); also elsewhere on the board
/Debug/LED_2: U5.9 (PC1); also elsewhere on the board
/EEPROM/~Write: U5.42 (PA9); also elsewhere on the board
/I2C_SCL: U5.41 (PA8); also elsewhere on the board
/I2C_SDA: U5.40 (PC9); also elsewhere on the board
/IMU/IMU_INT1: U5.54 (PD2); also elsewhere on the board
/IMU/IMU_INT2: U5.61 (PB8); also elsewhere on the board
/IMU/SPI_CS: U5.53 (PC12); also elsewhere on the board
/IMU/SPI_MISO: U5.56 (PB4(NJTRST)); also elsewhere on the board
/IMU/SPI_MOSI: U5.57 (PB5); also elsewhere on the board
/IMU/SPI_SCK: U5.55 (PB3(JTDO); also elsewhere on the board
/Microcontroller/ENC_0_SIG: U5.10 (PC2); also elsewhere on the board
/Microcontroller/ENC_1_SIG: U5.37 (PC6); also elsewhere on the board
/Microcontroller/HSE_IN: R15.2, U5.5 (PH0)
/Microcontroller/MOT_0_ENABLE: U5.21 (PA5); also elsewhere on the board
/Microcontroller/MOT_0_FAULT: U5.11 (PC3); also elsewhere on the board
/Microcontroller/MOT_0_IN_1: U5.23 (PA7); also elsewhere on the board
/Microcontroller/MOT_0_IN_2: U5.22 (PA6); also elsewhere on the board
/Microcontroller/MOT_0_IPROPI: U5.20 (PA4); also elsewhere on the board
/Microcontroller/MOT_0_MODE: U5.17 (PA3); also elsewhere on the board
/Microcontroller/MOT_1_ENABLE: U5.28 (PB2); also elsewhere on the board
/Microcontroller/MOT_1_FAULT: U5.38 (PC7); also elsewhere on the board
/Microcontroller/MOT_1_IN_1: U5.27 (PB1); also elsewhere on the board
/Microcontroller/MOT_1_IN_2: U5.26 (PB0); also elsewhere on the board
/Microcontroller/MOT_1_IPROPI: U5.25 (PC5); also elsewhere on the board
/Microcontroller/MOT_1_MODE: U5.29 (PB10); also elsewhere on the board
/Microcontroller/OSC_OUT: R15.1, Y1.3 (OUT)
/Microcontroller/SWCLK: U5.49 (PA14(JTCK); also elsewhere on the board
/Microcontroller/SWDIO: U5.46 (PA13(JTMS); also elsewhere on the board
/Microcontroller/UART_CRSF_TO_MCU: U5.52 (PC11); also elsewhere on the board
/Microcontroller/UART_GROWTH_TO_MCU: U5.36 (PB15); also elsewhere on the board
/Microcontroller/UART_MCU_TO_CRSF: U5.51 (PC10); also elsewhere on the board
/Microcontroller/UART_MCU_TO_GROWTH: U5.35 (PB14); also elsewhere on the board
/Microcontroller/USB_D+: U5.45 (PA12); also elsewhere on the board
/Microcontroller/USB_D-: U5.44 (PA11); also elsewhere on the board
/Microcontroller/USB_PRESENT: U5.50 (PA15(JTDI)); also elsewhere on the board
/Microcontroller/VBAT_SENSE: U5.24 (PC4); also elsewhere on the board
/SERVO_0: U5.14 (PA0); also elsewhere on the board
/SERVO_1: U5.15 (PA1); also elsewhere on the board
/SERVO_2: U5.16 (PA2); also elsewhere on the board
/SWD_nRST: C27.1, D5.1 (K), R13.2, SW2.2, U5.7 (NRST); also elsewhere on the board
unnamed: C28.1, U5.30 (VCAP)
unnamed: C29.1, U5.62 (VCAP)
unnamed: R14.1, SW3.2, U5.60 (BOOT0)
unnamed: TP10.1 (1_1), U5.43 (PA10)
unnamed: TP12.1 (1_1), U5.33 (PB12)
unnamed: TP13.1 (1_1), U5.34 (PB13)
unnamed: TP11.1 (1_1), U5.39 (PC8)
unnamed: C25.1, C26.1, FB1.2, U5.13 (VDDA)

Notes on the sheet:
Bypass Capacitors

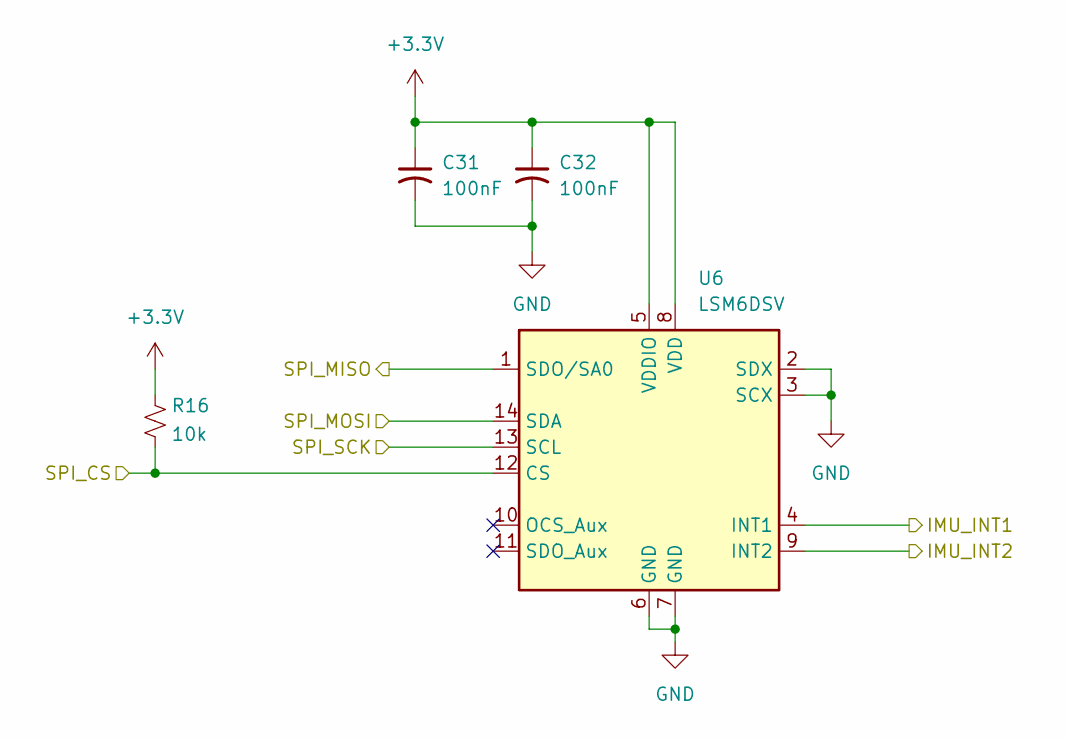
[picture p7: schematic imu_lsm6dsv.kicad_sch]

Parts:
C31, C32: 100nF; C_0603_1608Metric; Part No CC0603KRX7R9BB104; JLCPCB C14663
R16: 10k; R_0603_1608Metric; Part No 0603WAF1002T5E; JLCPCB C25804
U6: LSM6DSV; LGA-14_3x2.5mm_P0.5mm_LayoutBorder3x4y; JLCPCB C41785564

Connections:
/IMU/IMU_INT1: U6.4 (INT1); also elsewhere on the board
/IMU/IMU_INT2: U6.9 (INT2); also elsewhere on the board
/IMU/SPI_CS: R16.2, U6.12 (CS); also elsewhere on the board
/IMU/SPI_MISO: U6.1 (SDO/SA0); also elsewhere on the board
/IMU/SPI_MOSI: U6.14 (SDA); also elsewhere on the board
/IMU/SPI_SCK: U6.13 (SCL); also elsewhere on the board

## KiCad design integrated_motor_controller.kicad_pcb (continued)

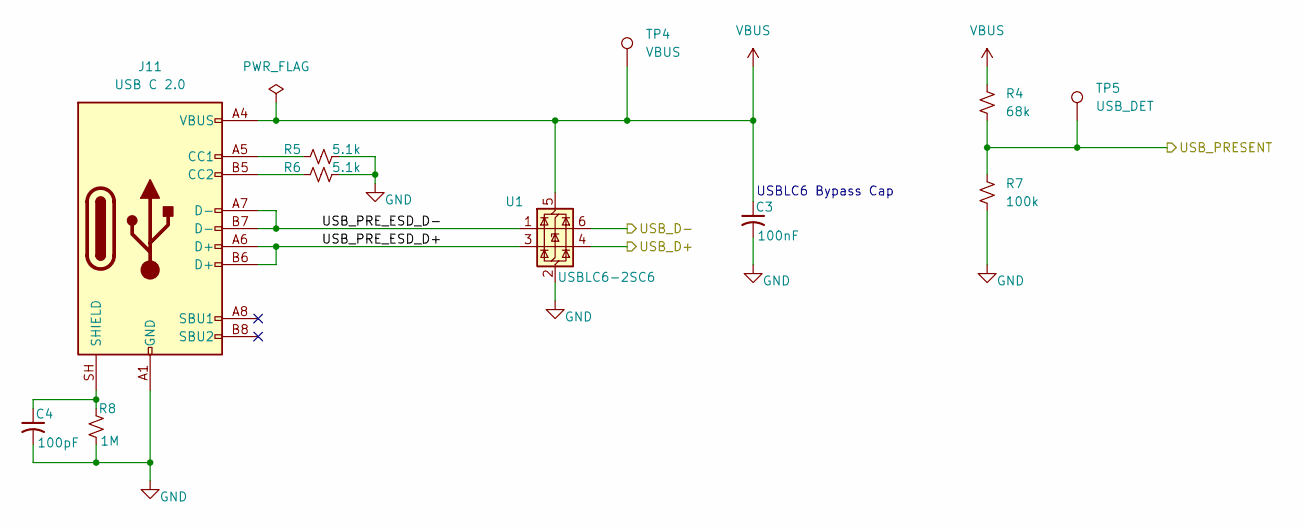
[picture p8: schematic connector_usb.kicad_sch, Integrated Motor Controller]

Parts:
C3: 100nF; C_0603_1608Metric; Part No CC0603KRX7R9BB104; JLCPCB C14663
C4: 100pF; C_0603_1608Metric; Part No CL10C101JB8NNNC; JLCPCB C14858
J11: USB C 2.0; USB_C_Receptacle_HRO_TYPE-C-31-M-12; Part No TYPE-C-31-M-12; JLCPCB C165948
R4: 68k; R_0603_1608Metric; Part No 0603WAF6802T5E; JLCPCB C23231
R5, R6: 5.1k; R_0603_1608Metric; Part No 0603WAF5101T5E; JLCPCB C23186
R7: 100k; R_0603_1608Metric; Part No 0603WAF1003T5E; JLCPCB C25803
R8: 1M; R_0603_1608Metric; Part No 0603WAF1004T5E; JLCPCB C22935
TP4: VBUS; TestPoint_Pad_D1.0mm; Part No ---; JLCPCB ---
TP5: USB_DET; TestPoint_Pad_D1.0mm; Part No ---; JLCPCB ---
U1: USBLC6-2SC6; SOT-23-6; Part No USBLC6-2SC6; JLCPCB C7519

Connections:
/Microcontroller/USB_D+: U1.4 (I/O2); also elsewhere on the board
/Microcontroller/USB_D-: U1.6 (I/O1); also elsewhere on the board
/Microcontroller/USB_PRESENT: R4.2, R7.1, TP5.1 (1_1); also elsewhere on the board
/USB Connector/USB_PRE_ESD_D+: J11.A6 (D+), J11.B6 (D+), U1.3 (I/O2)
/USB Connector/USB_PRE_ESD_D-: J11.A7 (D-), J11.B7 (D-), U1.1 (I/O1)
unnamed: J11.A5 (CC1), R5.1
unnamed: J11.B5 (CC2), R6.1
unnamed: C4.1, J11.SH (SHIELD), R8.1
VBUS: C3.1, J11.A4 (VBUS), J11.A9 (VBUS), J11.B4 (VBUS), J11.B9 (VBUS), R4.1, TP4.1 (1_1), U1.5 (VBUS); also elsewhere on the board

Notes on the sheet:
USBLC6 Bypass Cap

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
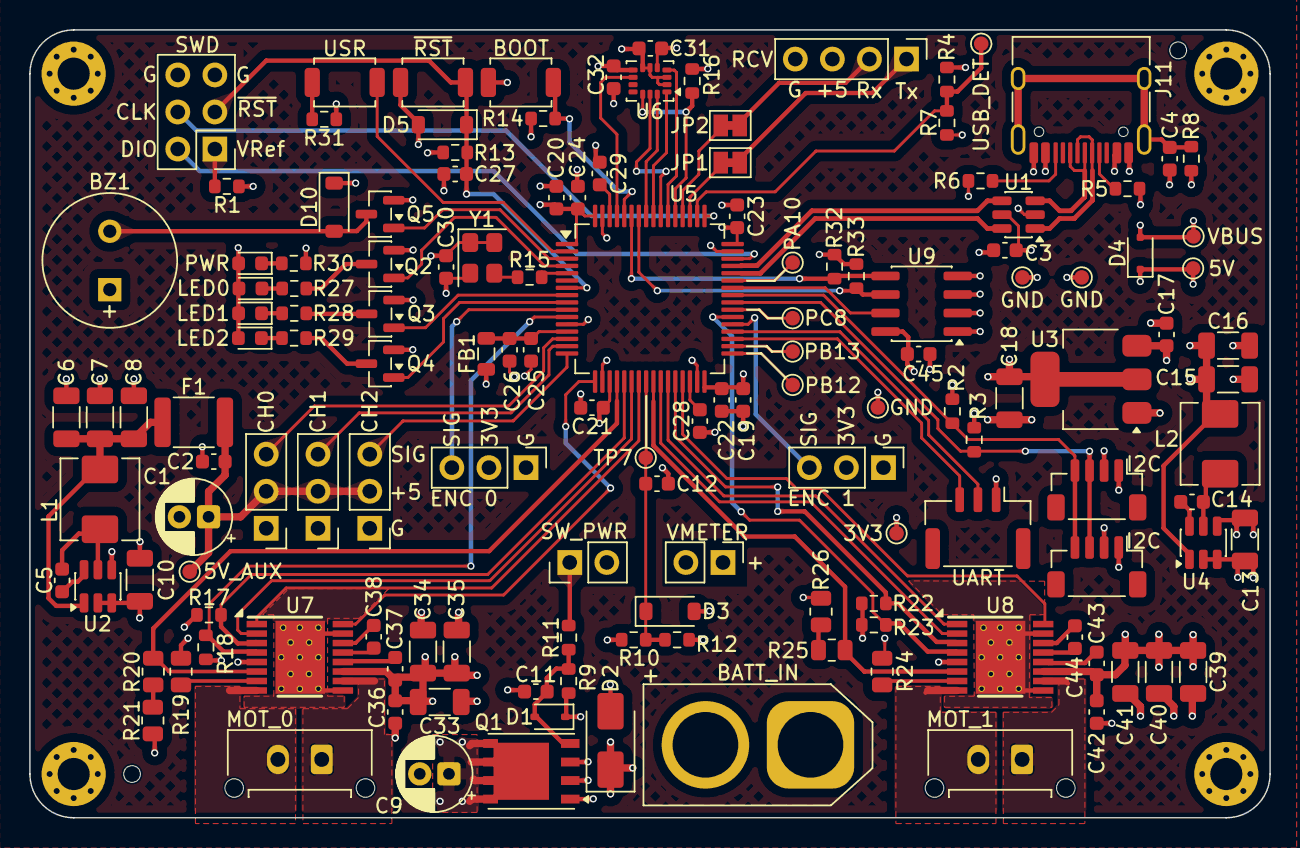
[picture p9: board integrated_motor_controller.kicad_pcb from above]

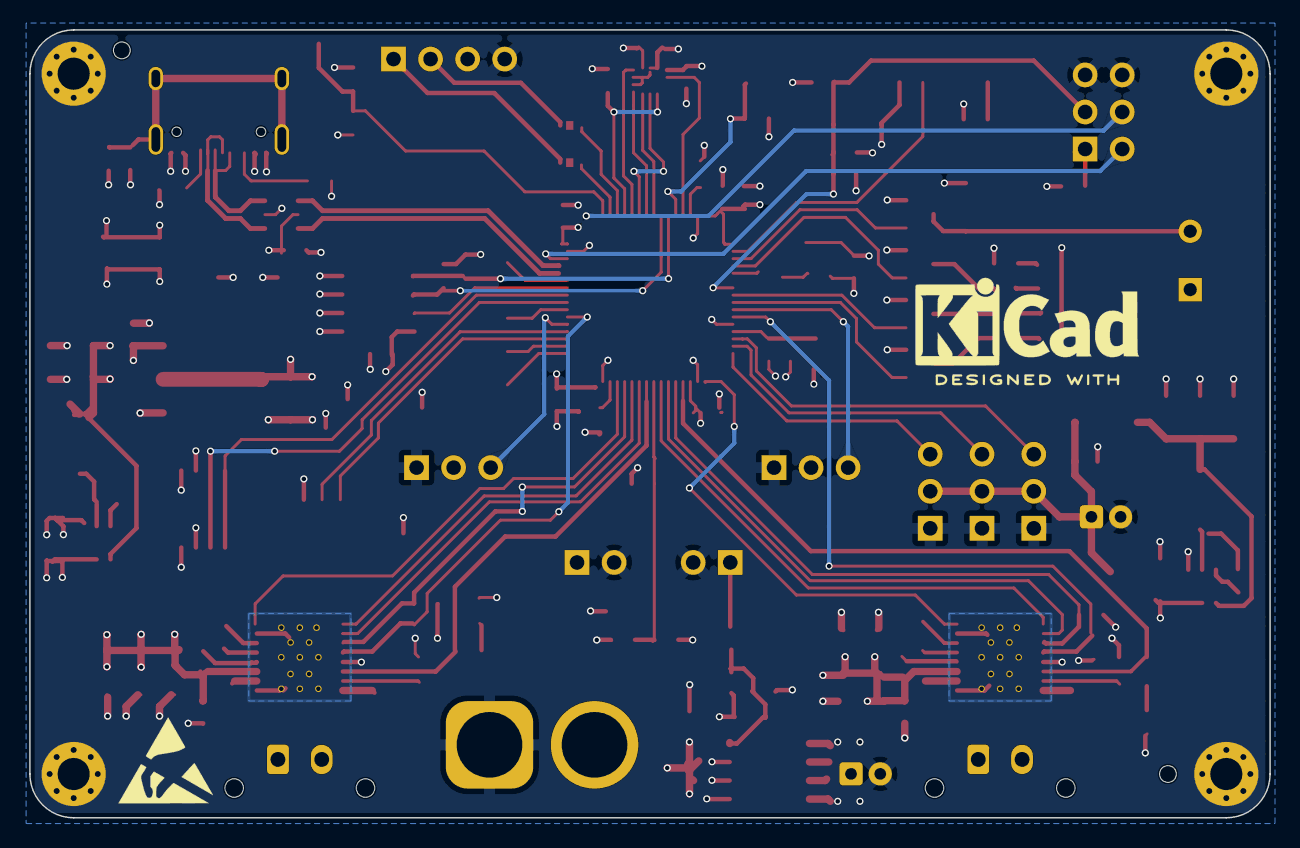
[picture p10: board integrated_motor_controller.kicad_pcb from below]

Board: 4 copper layers, 85.0 x 54.0 mm, 150 parts (2 on the bottom side), 99 nets.

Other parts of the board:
C45: 100nF; C_0603_1608Metric
R32, R33: 3.3k; R_0603_1608Metric

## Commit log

2026-05-10 Initial commit of the project files
    [connector_usb.kicad_sch, debug_leds.kicad_sch, eeprom_m24c64.kicad_sch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]
2026-05-10 Cleanup a comment in main schematic for the new project name
    [integrated_motor_controller.kicad_sch]
2026-05-11 Final edits before sending to fab
    [connector_usb.kicad_sch, debug_leds.kicad_sch, imu_lsm6dsv.kicad_sch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]
2026-05-12 Add comment on main sch for the mating connectors for I2C and UART
    [integrated_motor_controller.kicad_sch]
